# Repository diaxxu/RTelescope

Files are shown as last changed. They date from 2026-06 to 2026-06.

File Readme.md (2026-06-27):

# Rtelescope 
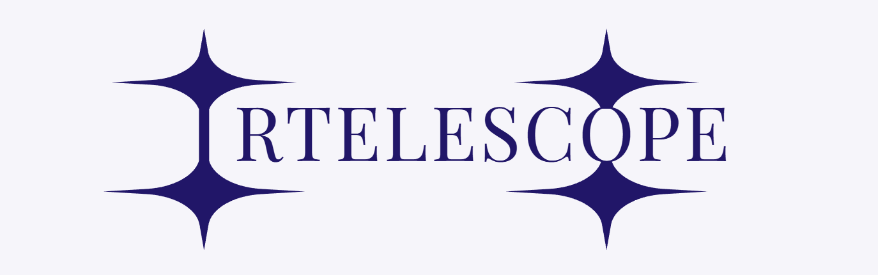
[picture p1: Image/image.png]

## What this is

Rocky V1 is a motorized, dual axis Alt Azimuth Dobsonian-style telescope mount that automatically finds and tracks deep-sky objects across the night sky. It pairs a high reduction mechanical drivetrain with a custom electronics shield built around hardware interpolated stepper microstepping, so the mount can move in tiny steps instead of big jerky motion you get from driving a stepper motor directly.

## Why I built it

**I built this telescope to see the wonders of the universe**. This is actually my first time ever using one! Since buying a telescope here is extremely expensive, I decided to build my own. I even built it with GoTo tracking, meaning it can track celestial bodies completely on its own without any external help 

## How it works

- **Altitude axis** : controls vertical elevation of the optical tube, counterbalanced for neutral equilibrium from 0° to 90°.
- **Azimuth axis** : controls horizontal rotation on a low-friction bearing track, full 360° pan.
- **Gear reduction** : a high-ratio reduction 
- **Electronics** : an ESP32-DevKitC drives two TMC2209 SilentStepStick modules (one per axis). MS1/MS2 on both drivers are hardware-strapped to lock in native 1/32 stepping, which the TMC2209 internally interpolates up to a smooth 1/256 microstep curve.
- **Power** : single 24V input through a screw terminal block, with 100µF electrolytic caps next to each driver's VM pin to absorb back-EMF spikes during fast GOTO slews.

---

# Electronics 

### Components 

Using cost-effective and available components to build a telescope tracking system :)

* **MCU: ESP32-WROOM-32E**
    * **Specifications:** 32-bit dual-core Xtensa LX6 microprocessor running at 240 MHz, with 520 KB SRAM and 4 MB flash memory.

* **Driver: TMC2209 Stepper Motor Driver**
    * **Specifications:** Ultra silent motor driver for two-phase stepper motors  handles up to 2.8A peak current (2A RMS) per motor supports up to 1/256 microstepping.

* **Power: 24V DC Power Supply**
    * **Specifications:** 24V step-down switching power supply 

### Schematics 

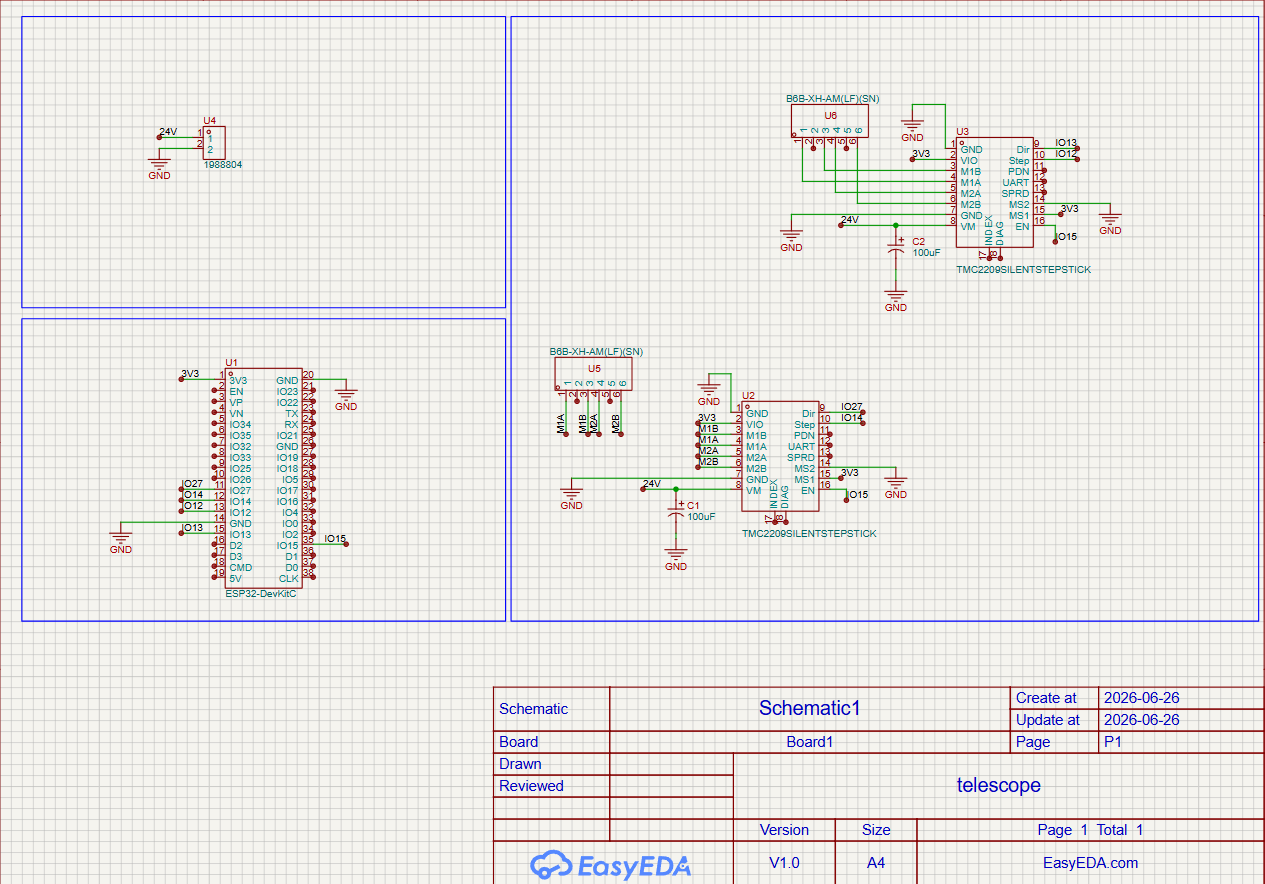
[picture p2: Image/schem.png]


### Routing 

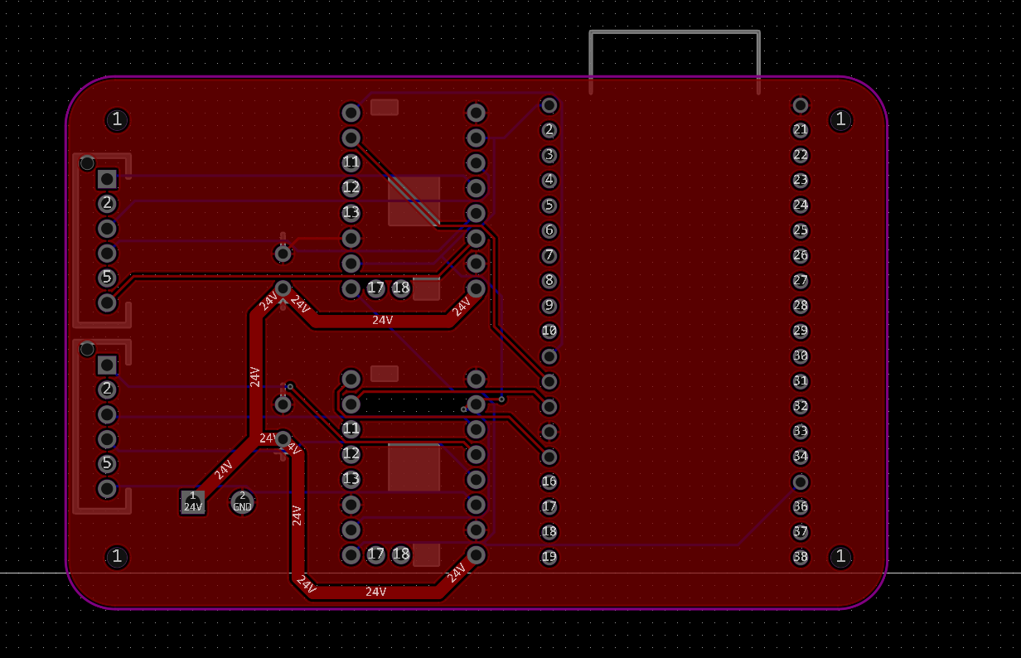
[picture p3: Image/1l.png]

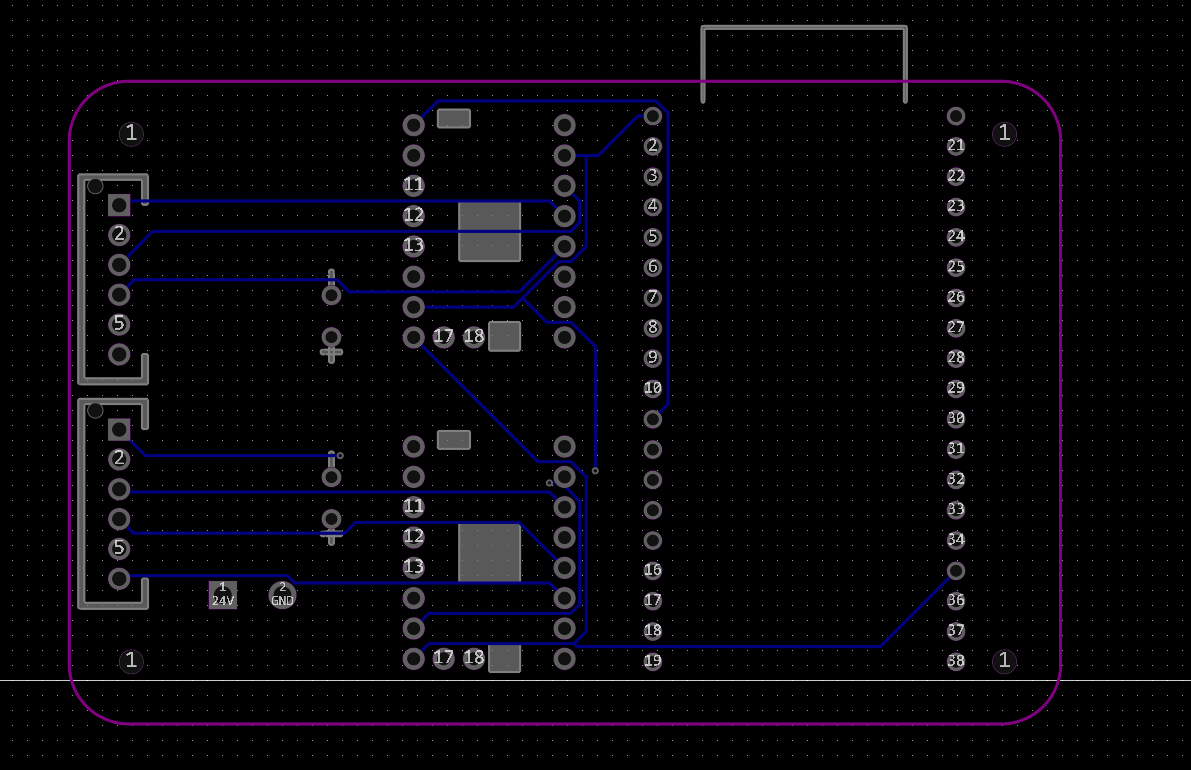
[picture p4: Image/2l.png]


### 3D

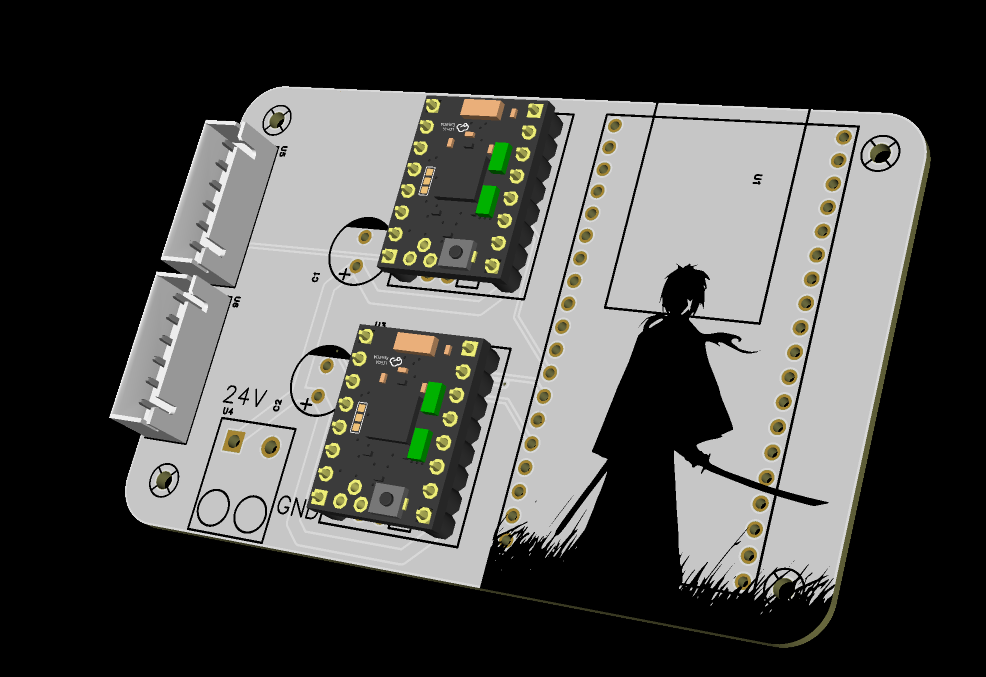
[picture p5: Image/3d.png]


---
# Telescope 

For this telescope, I chose a 150mm primary mirror to catch more light, combined with a 30mm secondary and a 6mm eyepiece. This setup provides a really sharp picture of the moon and can easily see the rings of Saturn. It’s also super convenient because the upper assembly can extend and retract with built-in limiters. Plus, it's fully motorized with NEMA 17 motors for 2-axis movement (altitude and azimuth), and it's incredibly smooth since both axes have really high reduction ratios.

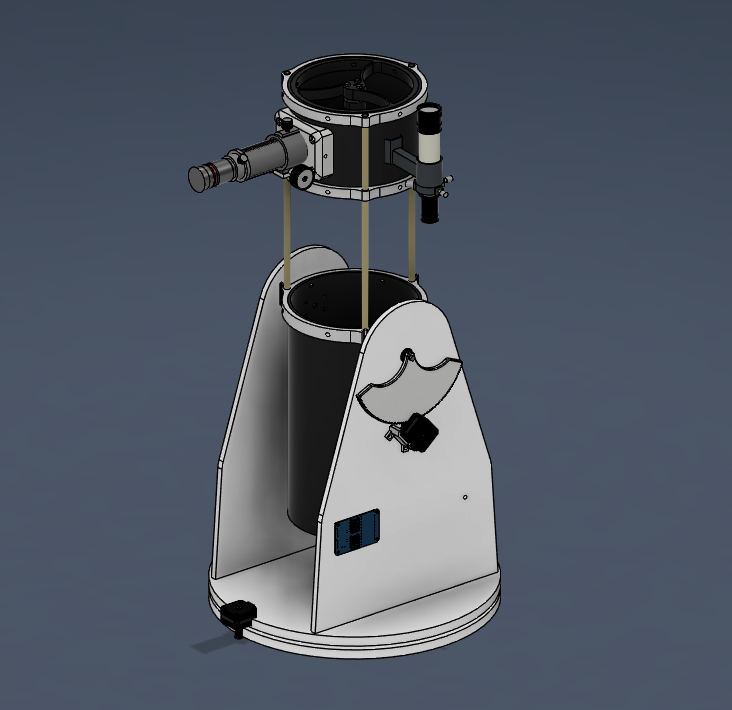
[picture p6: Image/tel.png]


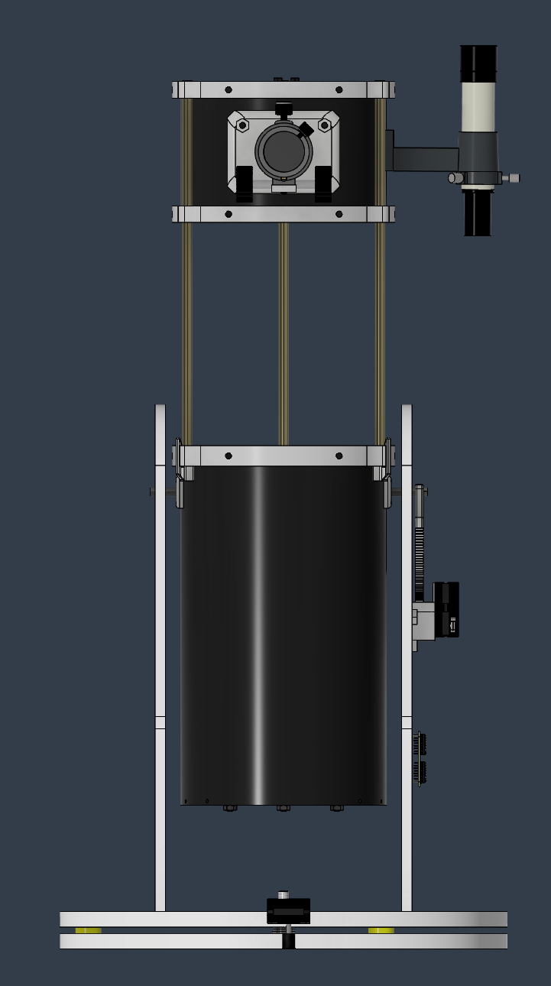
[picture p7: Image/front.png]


---
## How to use it 

### Step 1: Primary and Secondary Optical Assembly
1. **Mount the Primary Mirror:** 
2. **Assemble the Adjustable Rear Cell:** 
3. **Install the Secondary Spider:** 
4. **Mount the Secondary Mirror:** 
5. **Install the Focuser:**

---

### Step 2: Retractable Upper Truss Assembly
1. **Fit the Moving Tubes:** 
2. **Install the Built-in Limiters:** 
3. **Test Mechanical Clearance:**

---

### Step 3: Base Panel Fabrication & Pocket Assembly
1. **Prepare Layered Laser Files:**
2. **Laser Cut the Wood:** 
3. **Stack and Glue the Pocket:** 
---

### Step 4: Alt-Azimuth Mount & Gearing Drivetrain
1. **Build the Azimuth Turntable:** 
2. **Mount the Altitude Axis:** 
3. **Install the NEMA 17 Stepper Motors:** 
4. **Setup the High-Ratio Gear Reductions:** 
---

### Step 5: Custom PCB Electronics Integration
1. **Populate the Motherboard (U1):** 
2. **Install the Driver Modules (U2, U3):** 
3. **Configure Hardware Microstepping Strapping:** 
4. **Connect Control Signals:** 
5. **Wire the Motor Headers:** 
6. **Connect Filtration & Power:** 

---

### Step 6: Power-On Calibration & Tuning
1. **Calibrate Driver Voltage (Vref):** 
2. **Select Tracking Mode Profile:** 
---
### Wire Diagram 
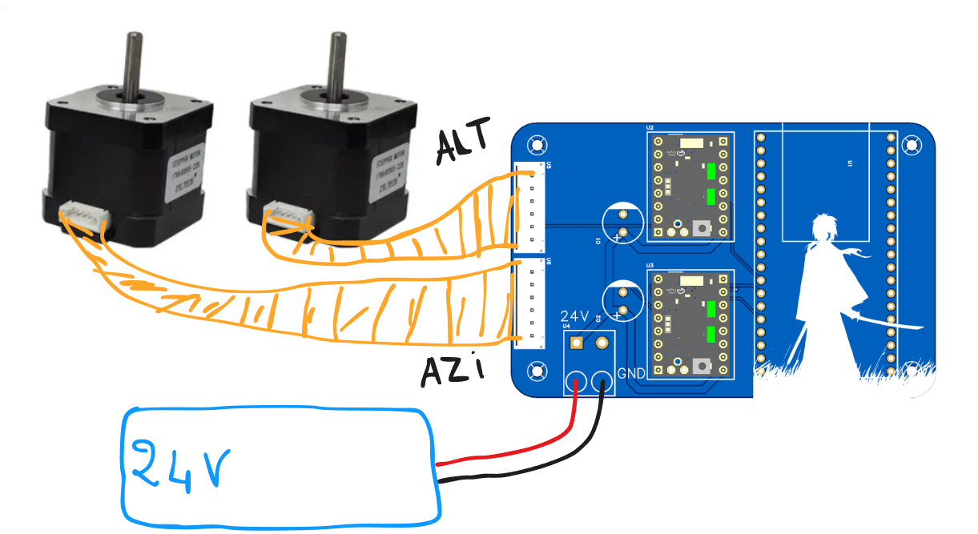
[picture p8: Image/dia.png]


---

# BOM 
revised bill of materials
see the full version in BOM.csv

| Item | Qty | Price (USD) | Info |
| :--- | :---: | :---: | :--- |
| Primary, secondary telescope mirrors | 1 | $60.25 | 150F750 + 30mm |
| Focuser | 1 | $21.37 | Focuser by adjusting the eyepiece |
| Eyepiece | 1 | $56.58 | 6mm |
| Finder scope | 1 | $9.81 | |
| PVC tube | 1 | $9.06 | 200mm diameter |
| Teflon pads | 8 | $7.11 | For removing friction |
| 3D printing shipping | 1 | $40.00 | Shipping from Legion |
| TMC2209 | 2 | $14.24 | Driving the steppers |
| PCB | 5 | $13.04 | From JLCPCB with coupons |
| Tube | 1 | $5.86 | The extruding tube 4m 10mm |
| MDF WOOD for mounts | 1 | $21.31 | Wood to make the mounts |
| Laser cutting fee | 1 | $30.00 | Laser cut the mdf wood |
| ESP32 WROOM32 | 1 | $3.22 | |
| Capacitors | 10 | $6.28 | 100uF electrolytic |
| Stepper motor | 2 | $29.80 | NEMA 17 |
| Screws, nuts | 1 | $20.54 | M6 nuts and screws and M3 |
| Washers | 20 | $3.22 | |
| Black paint aerosol | 1 | $5.22 | To paint the interior of PVC black |
| Silicone adhesive | 1 | $2.93 | Glueing the primary mirrors |
| **TOTAL** | | **$359.84 USD** | |

---

# Pics

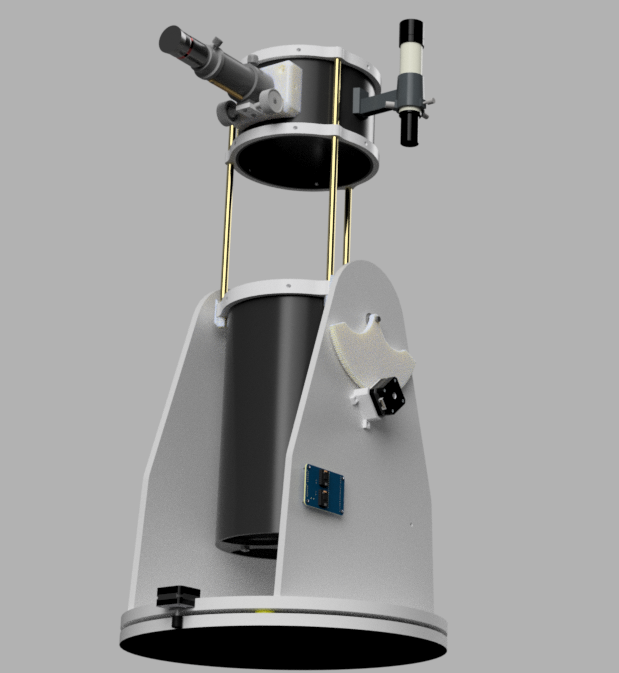
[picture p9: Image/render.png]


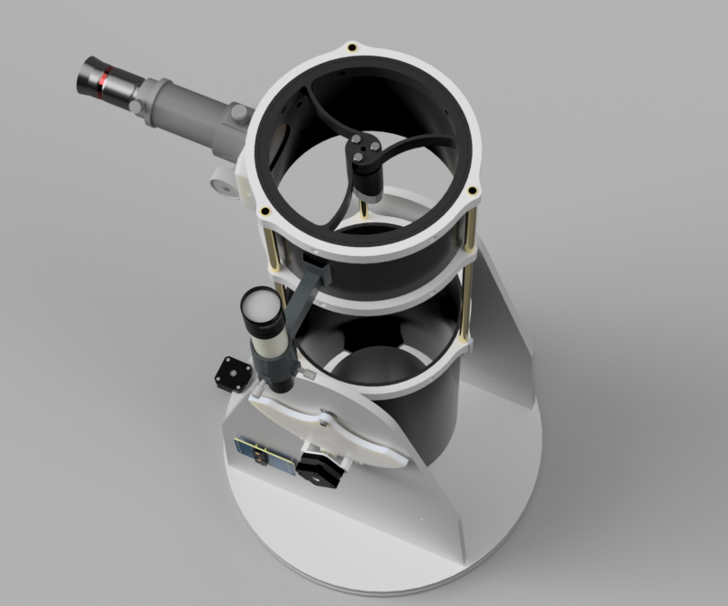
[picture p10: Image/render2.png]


---
## License

MIT License, see LICENSE.

 Free to build, modify, and share. Please
credit the project if you publish your own build based on this one.

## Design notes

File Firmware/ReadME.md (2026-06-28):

# How to Install OnStep on your ESP32

To get this firmware running on your microcontroller, follow these steps:

### 1. Download the OnStep Source Code
Because OnStep is actively updated, you need to grab the source directly from the official repository:
* Download the official source code from the [OnStep GitHub Repository](https://github.com/hjd1964/OnStepX).

### 2. Swap the Configuration Files
Before compiling, you must overwrite OnStep's generic templates with the custom hardware configurations built for this specific telescope project:
1. Copy the `Config.h` and `PinMap.h` files from *this* folder.
2. Paste them into the main directory of the downloaded OnStep source folder, replacing the default files.

### 3. Set Up Your Arduino IDE
If you haven't configured your Arduino IDE for ESP32 development yet, set it up using these steps:
1. Open Arduino IDE and go to **File** > **Preferences**.
2. In the *Additional Boards Manager URLs* field, paste the official ESP32 link:
   `https://raw.githubusercontent.com/espressif/arduino-esp32/gh-pages/package_esp32_index.json`
3. Go to **Tools** > **Board** > **Boards Manager...**, search for **esp32** by Espressif, and click **Install**.

### 4. Compile and Flash
1. Open the main OnStep project file (`.ino`) in your Arduino IDE.
2. Connect your ESP32 to your computer using a data-capable USB cable.
3. In the IDE menu, go to **Tools** > **Board** and select your specific module (typically **ESP32 Dev Module**).
4. Select the correct COM port under **Tools** > **Port**.
5. Click the **Upload** arrow button in the top left. 

Once the IDE finishes compilation and says *Done Uploading*, the ESP32 will reboot and immediately begin hosting a Wi-Fi hotspot named `RTelescope`.

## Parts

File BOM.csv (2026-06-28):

item | qty | price usd | info | link
Primary , secondary telescope mirros | 1 | 60.25 | 150F750 + 30mm | https://www.aliexpress.com/item/1005002663239801.html?spm=a2g0o.cart.0.0.43b8378dwgW6WL&mp=1
Focuser | 1 | 21.37 | focuse by adjusting the eyepiece | https://www.aliexpress.com/item/1005008985112032.html?spm=a2g0o.cart.0.0.43b8378dwgW6WL&mp=1
eye piece | 1 | 56.58 | 6mm | https://www.aliexpress.com/item/1005010558875774.html?spm=a2g0o.cart.0.0.43b8378dwgW6WL&mp=1
Finder scope | 1 | 9.81 |  | https://www.aliexpress.com/item/1005004505440739.html?spm=a2g0o.cart.0.0.43b8378dwgW6WL&mp=1
Pvc tube | 1 | 9.06 | 200mm diameter | https://bnova.ma/product/tube-pinoplast-o200-orange-6m/
teflon pads | 8 | 7.11 | for removing friction | https://www.aliexpress.com/item/1005008788713900.html?spm=a2g0o.cart.0.0.43b8378dwgW6WL&mp=1
3d printing shipping | 1 | 40 | shipping from legion | https://printlegion.hackclub.com/
tmc2209 | 2 | 14.24 | driving the steppers | https://www.aliexpress.com/item/1005008819518658.html
PCB | 5 | 13.04 | From JLCpcb with coupons | https://cart.jlcpcb.com/shopcart/cart/
tube | 1 | 5.86 | the extruding tube 4m 10mm | https://bnova.ma/product/tube-cuivre-10mm/
MDF WOOD for mounts | 1 | 21.31 | wood to make the mounts | locally
laser cutting fee | 1 | 30 | laser cut the mdf wood | locally
esp32 wroom32 | 1 | 3.22 |  | https://www.aliexpress.com/item/1005004685935016.html
Capacitors | 10 | 6.28 | 100uF electrolytic | https://www.aliexpress.com/item/1005002075527957.html
Stepper motor | 2 | 29.8 | nema 17 | https://www.aliexpress.com/ssr/300000512/BundleDeals2?productIds=1005010439456118%3A12000052414142167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
screws, nuts | 1 | 20.54 | all the neccesary nuts and screws for this whole project | https://www.aliexpress.com/item/1005005971756266.html https://www.aliexpress.com/item/1005007278965396.html?mp=1
washers | 20 | 3.22 |  | https://www.aliexpress.com/item/1005007625630719.html
black paint aerosol | 1 | 5.22 | to paint the interior of pvc black | https://mrbricolage.ma/produit/aerosol-peinture-ral-6/
silicone adhesive | 1 | 2.93 | glue'ing the primary mirrors | https://www.aliexpress.com/item/1005011532501535.html?spm=a2g0o.cart.0.0.26e6378dvaomam&mp=1
 |  | TOTAL : 359.84 USD

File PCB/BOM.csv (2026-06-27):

No. | Quantity | Comment | Designator | Footprint | Value | Manufacturer Part | Manufacturer | Supplier Part | Supplier | LCSC Price | JLCPCB Stock | JLCPCB Price
1 | 2 | 100uF | C1,C2 | CAP-TH_BD8.0-P3.50-D0.6-FD-H10.0 | 100uF | 100uF35V8x11GF | Econd(米朗电子) | C49304899 | LCSC |  | 4602 | 0.0042
2 | 4 | Screw-Hole-M2 | SCREW1,SCREW2,SCREW3,SCREW4 | Screw-Hole-M2 |  |  |  |  |  | 8.4476
3 | 1 | ESP32-DevKitC | U1 | BULETM-SMD_ESP32-DEVKITC |  | ESP32-DevKitC | ESPRESSIF(乐鑫) | C571180 | LCSC |  | 0
4 | 2 | TMC2209SILENTSTEPSTICK | U2,U3 | COMM-TH_TMC2209SILENTSTEPSTICK |  | TMC2209SILENTSTEPSTICK | TRINAMIC | C17375345 | LCSC |  | 0 | 0.6161
5 | 1 | 1988804 | U4 | CONN-TH_1988804 |  | 1988804 | Phoenix Contact(菲尼克斯) | C7168402 | LCSC |  | 14 | 0.1192
6 | 2 | B6B-XH-AM(LF)(SN) | U5,U6 | CONN-TH_6P-P2.50_B6B-XH-AM-LF-SN |  | B6B-XH-AM(LF)(SN) | JST | C161873 | LCSC |  | 5326 | 0.0236

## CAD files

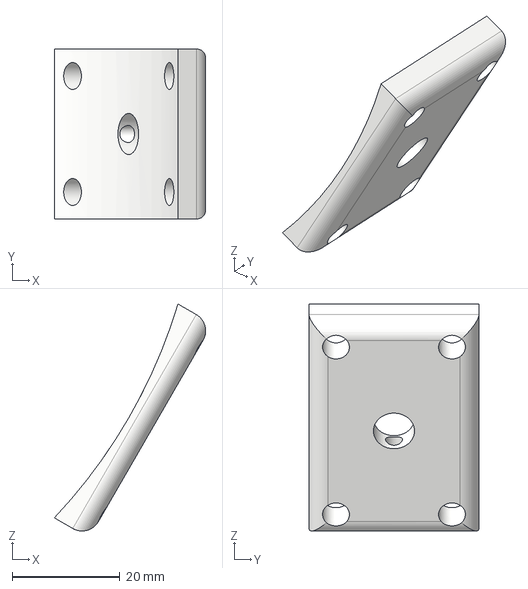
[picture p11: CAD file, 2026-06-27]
CAD/3d printables/Component17.step
28.1 x 31.6 x 42.2 mm

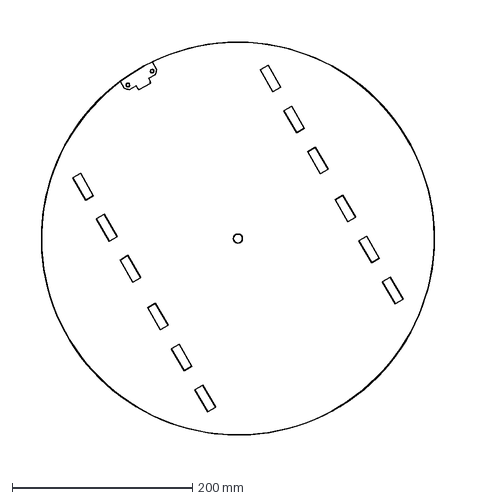
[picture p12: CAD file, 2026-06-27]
CAD/Laser cut/dxf/upper mount.dxf
492.2 x 493.0 mm

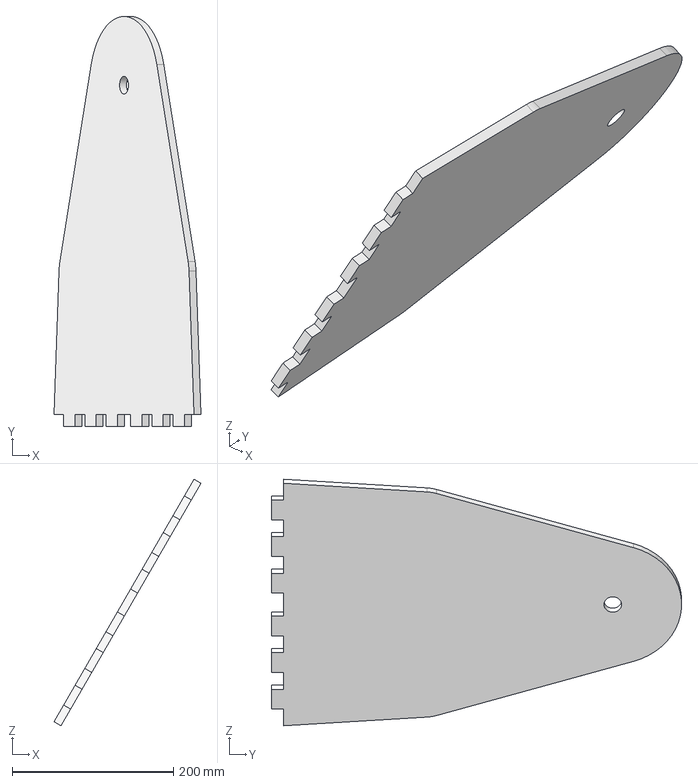
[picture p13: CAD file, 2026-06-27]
CAD/Laser cut/step/vertical mount Left.step
182.3 x 508.5 x 305.8 mm

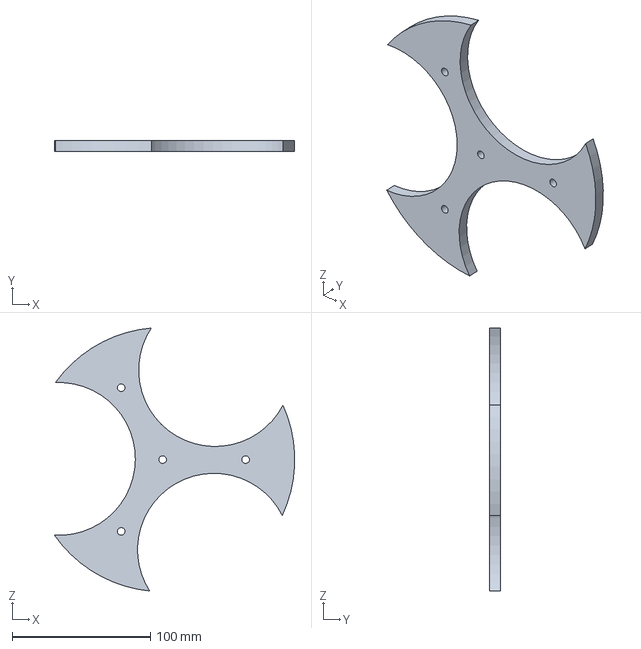
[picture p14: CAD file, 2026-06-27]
CAD/3d printables/bottom.step
173.7 x 8.00 x 190.2 mm

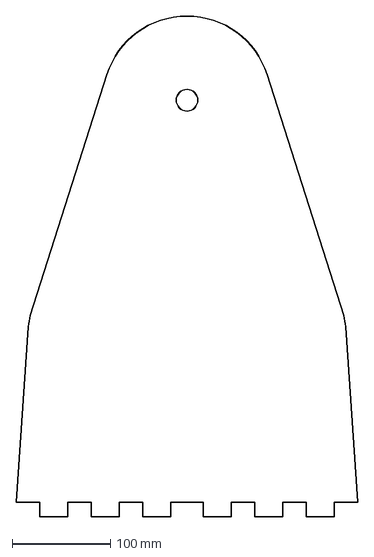
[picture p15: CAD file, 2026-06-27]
CAD/Laser cut/dxf/top mount Left.dxf
347.3 x 508.6 mm

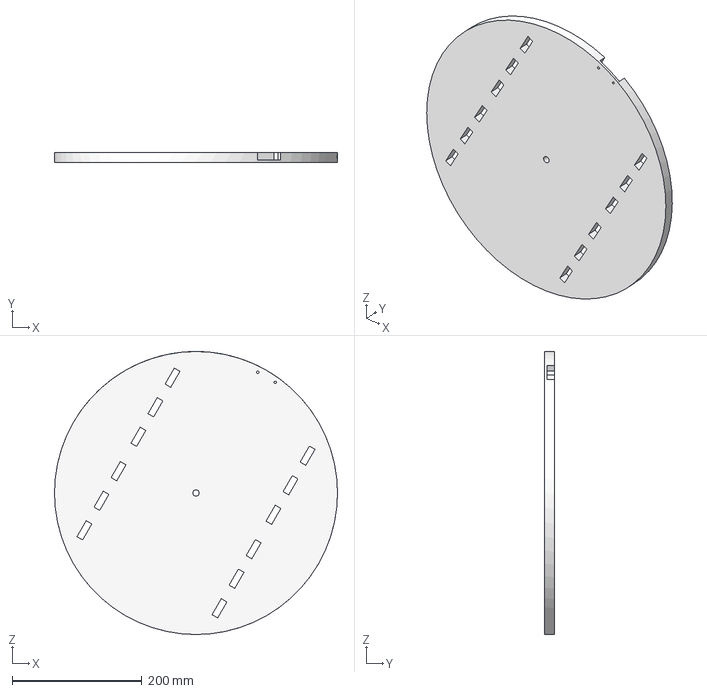
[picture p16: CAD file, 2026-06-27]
CAD/Laser cut/step/Top mount.step
435.5 x 15.0 x 435.5 mm

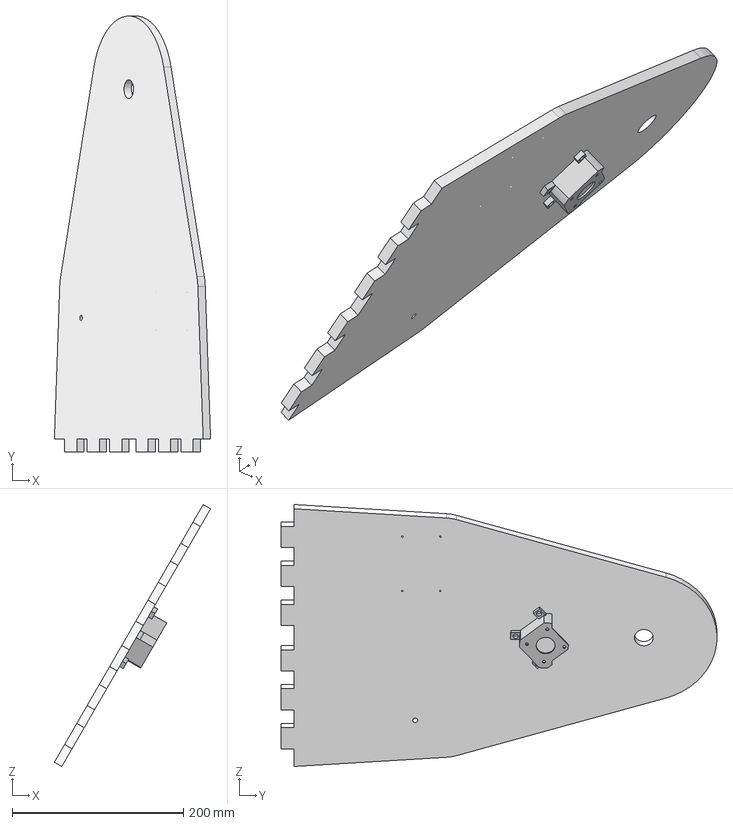
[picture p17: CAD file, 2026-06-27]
CAD/Laser cut/step/vertical mount right.step
182.3 x 508.5 x 305.8 mm

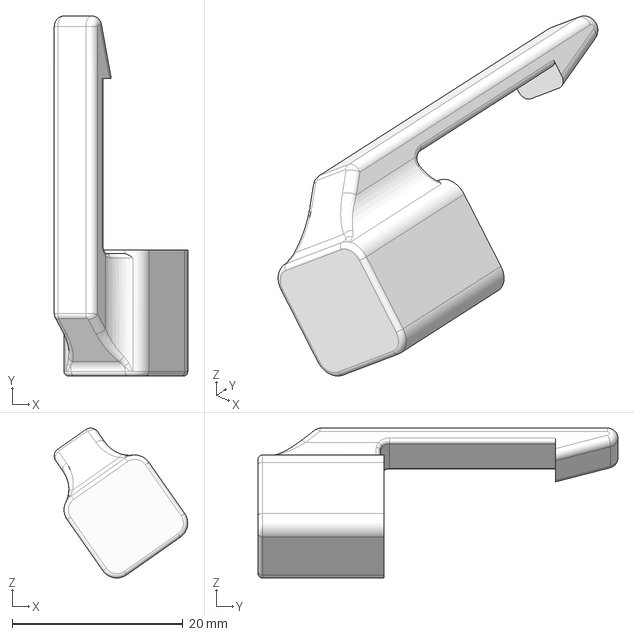
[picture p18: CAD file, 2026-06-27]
CAD/3d printables/limit.step
15.7 x 42.2 x 17.6 mm

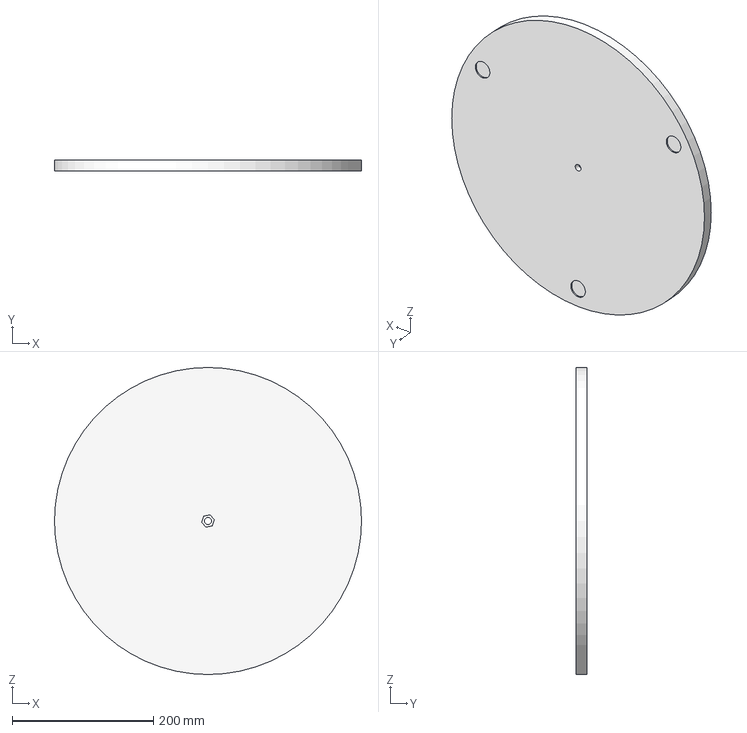
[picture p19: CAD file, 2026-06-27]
CAD/Laser cut/step/Bottom mount.step
435.5 x 15.0 x 435.5 mm

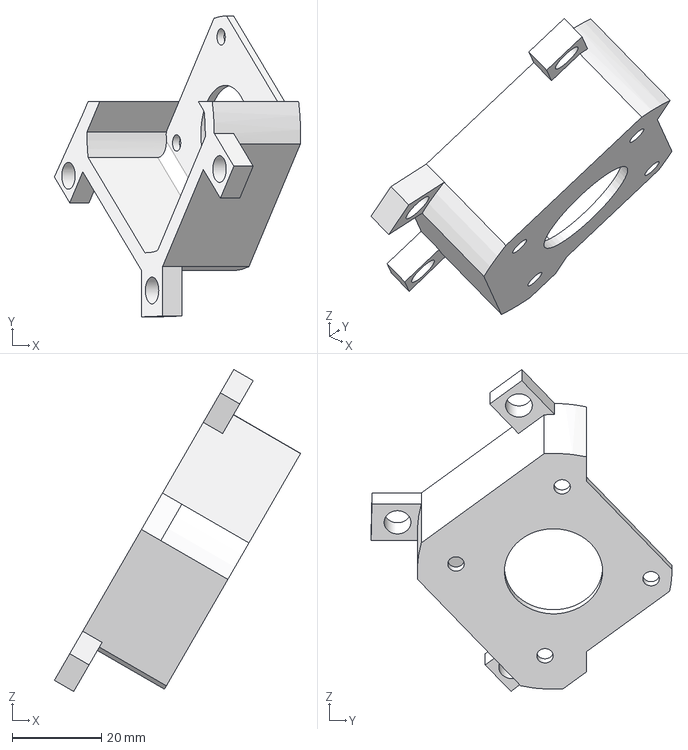
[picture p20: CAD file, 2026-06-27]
CAD/3d printables/Component80.step
55.1 x 67.3 x 72.1 mm

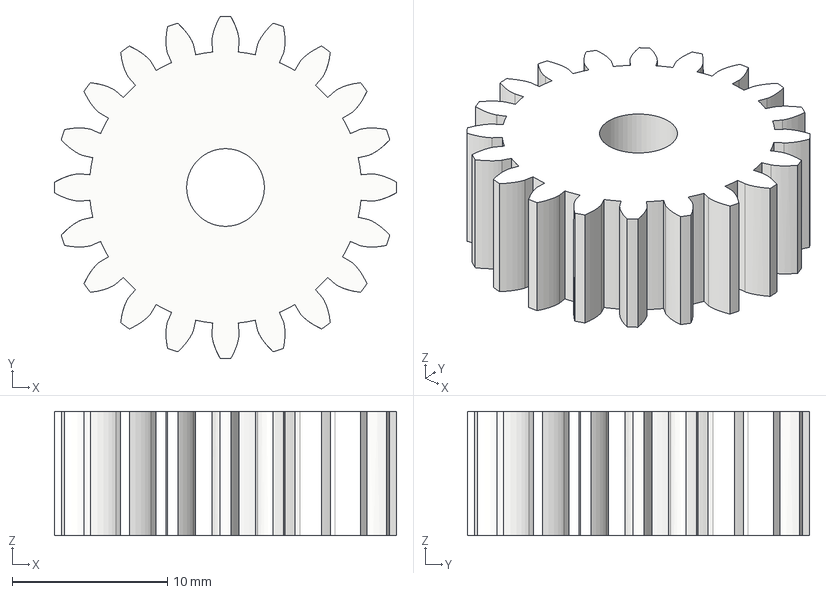
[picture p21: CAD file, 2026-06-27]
CAD/3d printables/Component78.step
22.0 x 22.0 x 8.00 mm

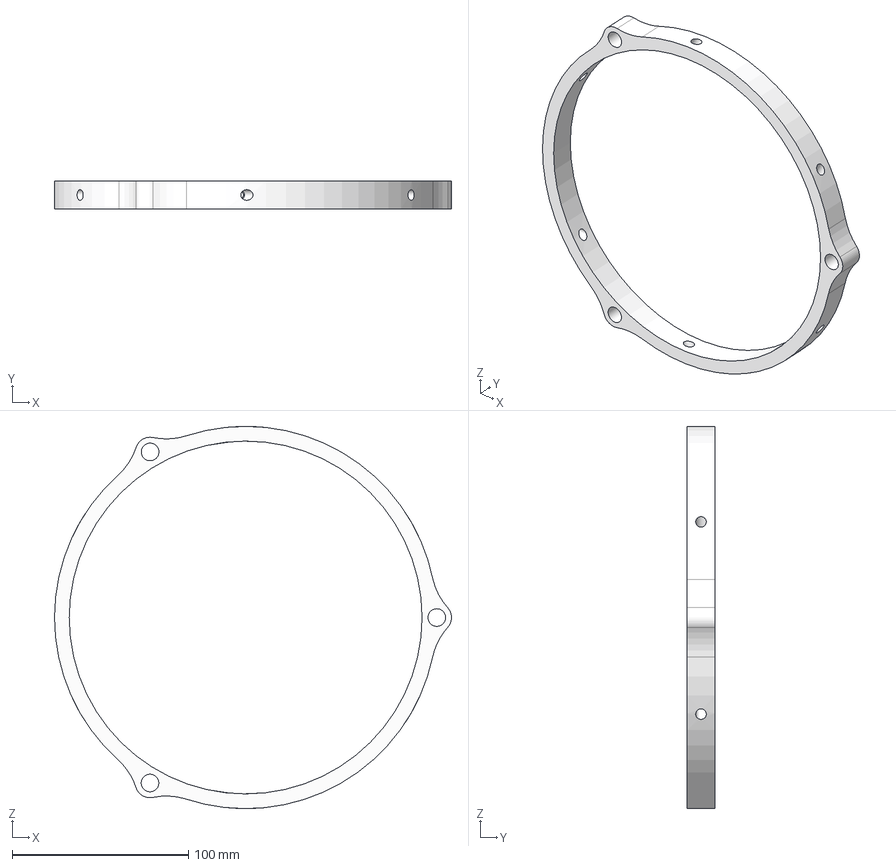
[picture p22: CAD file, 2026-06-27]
CAD/3d printables/3d print top 2.step
225.0 x 16.0 x 216.7 mm

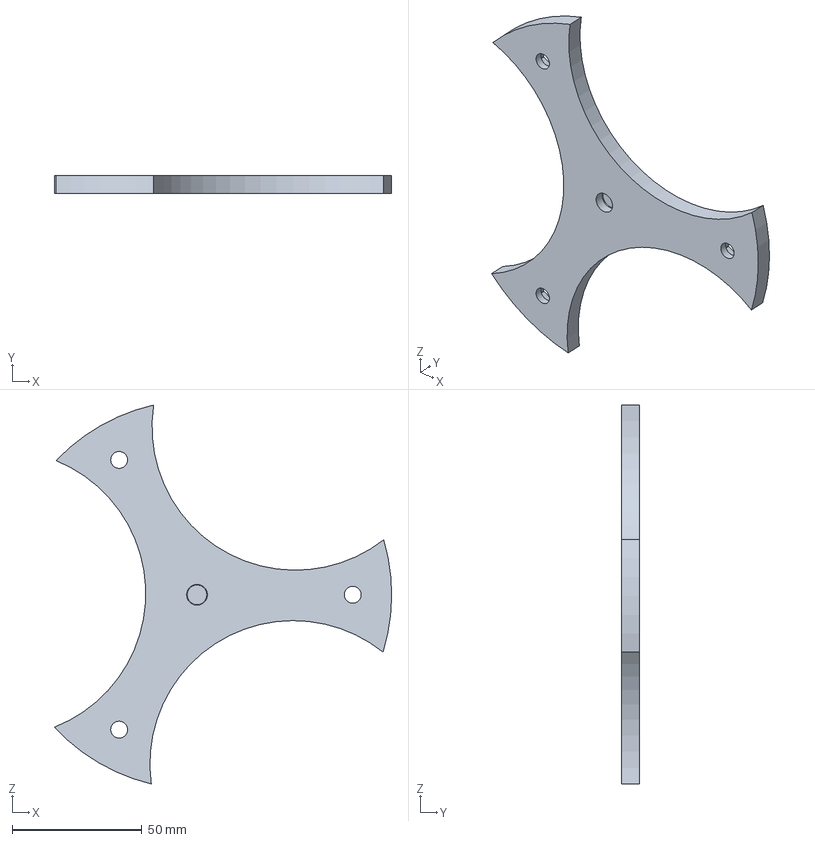
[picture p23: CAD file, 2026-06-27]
CAD/3d printables/TOP.step
130.0 x 7.00 x 146.0 mm

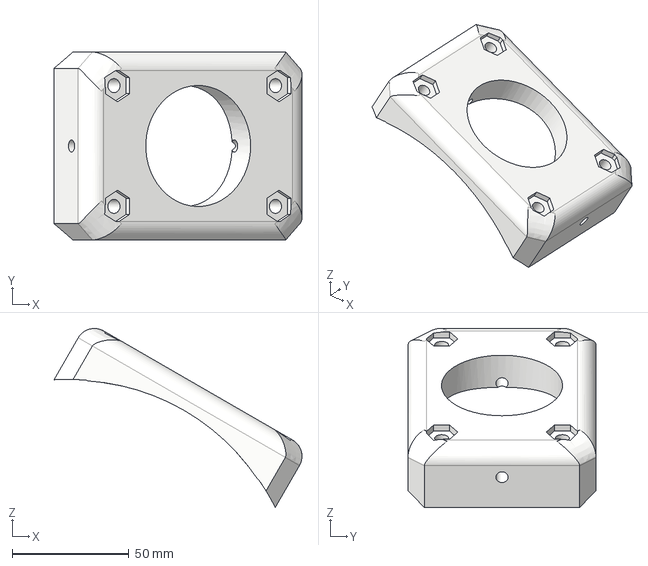
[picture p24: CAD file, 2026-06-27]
CAD/3d printables/c-mount.step
106.4 x 80.7 x 76.8 mm

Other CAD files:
CAD/3d printables/Component17(Mirror).step
CAD/3d printables/3d print top 1.step
CAD/3d printables/3d print bottom.step
CAD/3d printables/Spyder.step
CAD/3d printables/limit (1).step
CAD/3d printables/limit (2).step
CAD/3d printables/spyder mount.step
CAD/Laser cut/dxf/bottom mount.dxf
CAD/Laser cut/dxf/top mount.dxf
CAD/assembly/RTelescope.f3z

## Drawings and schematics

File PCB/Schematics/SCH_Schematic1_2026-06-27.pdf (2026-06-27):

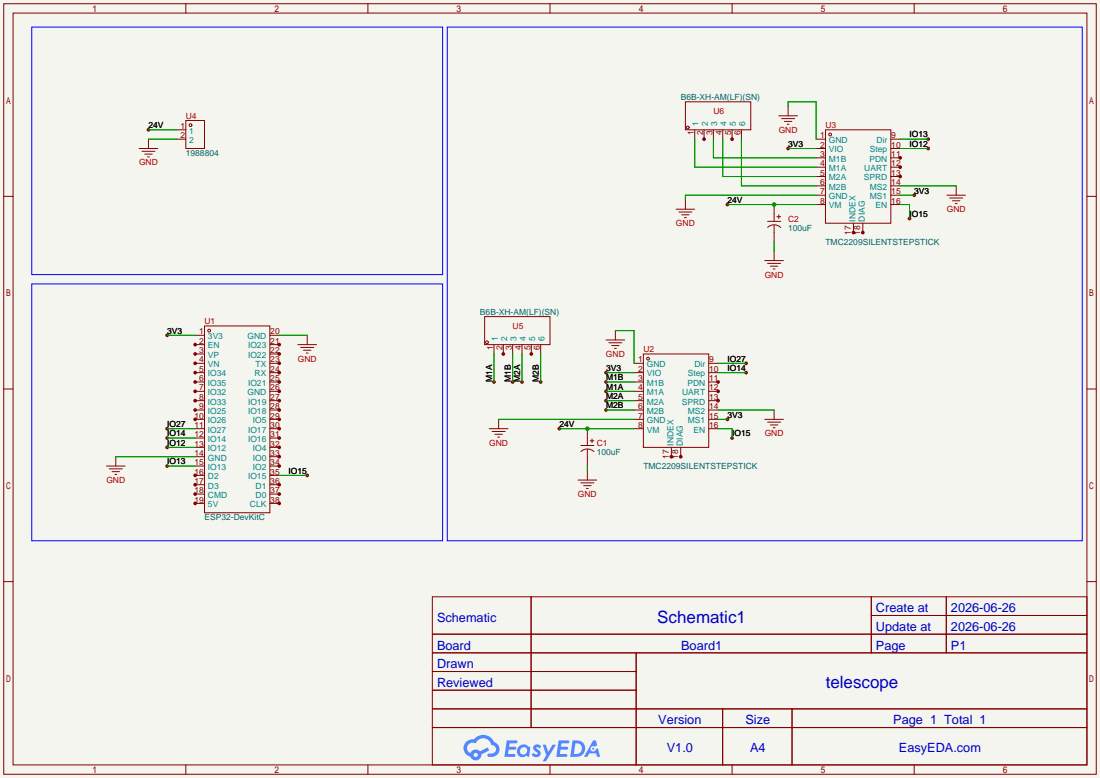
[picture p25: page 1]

Schematic | Schematic1 | Create at | 2026-06-26

Update at | 2026-06-26

Board | Board1 | Page | P1
Drawn | | telescope
Reviewed

Version | Size | Page 1 Total 1
V1.0 | A4 | EasyEDA.com

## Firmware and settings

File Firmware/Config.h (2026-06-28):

#ifndef CONFIG_H
#define CONFIG_H

#define MOUNT_TYPE     ALT_AZ
#define MOUNT_NAME     "Rtelescope"

#define MULTI_STEPS_RA   32
#define MULTI_STEPS_DEC  32

#define MOTOR_STEPS_RA   200
#define MOTOR_STEPS_DEC  200

#define GEAR_RATIO_RA    120.0
#define GEAR_RATIO_DEC   120.0

#define STEPS_PER_DEGREE_RA  ((MOTOR_STEPS_RA * MULTI_STEPS_RA * GEAR_RATIO_RA) / 360.0)
#define STEPS_PER_DEGREE_DEC ((MOTOR_STEPS_DEC * MULTI_STEPS_DEC * GEAR_RATIO_DEC) / 360.0)

#define SLEW_RATE_MAX   4.0
#define TRACKING_RATE_DEFAULT TRACK_SIDEREAL

#define DRIVER_TYPE_RA  TMC2209
#define DRIVER_TYPE_DEC TMC2209

#define WIFI_ENABLED    true
#define WIFI_SSID       "RTelescope"
#define WIFI_PASSWORD   "wonders_of_universe"

#endif

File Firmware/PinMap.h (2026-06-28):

#ifndef PINMAP_H
#define PINMAP_H

#define RA_STEP_PIN    12
#define RA_DIR_PIN     14
#define RA_ENABLE_PIN  13

#define DEC_STEP_PIN   25
#define DEC_DIR_PIN    26
#define DEC_ENABLE_PIN 27

#define LED_PIN        2
#define WIFI_STATUS_PIN 5

#endif

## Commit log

2026-06-27 Initial commit with LFS
    [1_P1.schdoc, 3d print bottom.step, 3d print top 1.step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]
2026-06-27 Revise Readme.md for improved structure and content
    Updated the Readme.md to enhance clarity and organization, including sections on electronics, telescope specifications, usage instructions, BOM, and images.
2026-07-06 Rename 'How to use it' section to 'Assembly'
2026-11-09 Update ReadME.md
    Updated installation instructions for OnStep firmware on ESP32.
